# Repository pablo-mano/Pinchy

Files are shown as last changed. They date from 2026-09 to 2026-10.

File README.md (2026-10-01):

# Pinchy

**TODO — Firmware:** No firmware source code or flashable binaries are included in this repository. Firmware development and publication are deferred. See [TODO](TODO.md).

**A raspberry desktop companion by Paweł Manowiecki · [X: @pawel_mano](https://x.com/pawel_mano)**

[Polski](README_PL.md) · [Live 3D explorer](https://pablo-mano.github.io/Pinchy/) · [Print files](printing/README.md) · [BOM](electronics/BOM.md) · [Wiring](electronics/WIRING.md) · [Assembly](docs/ASSEMBLY.md) · [Films](videos/README.md)

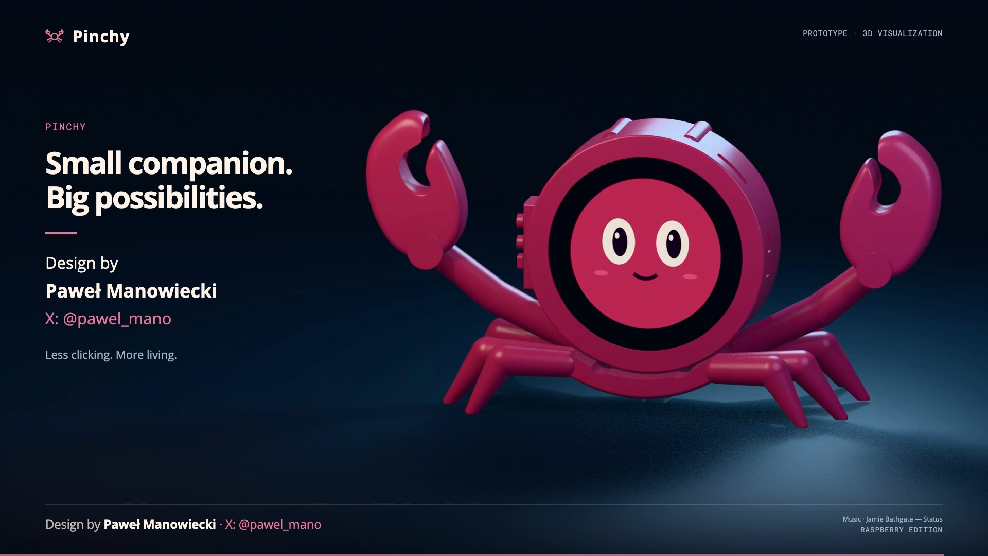
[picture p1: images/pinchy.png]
Pinchy — raspberry desktop companion


“**Hey Pinchy!**” — a small crab-shaped companion built around the **Waveshare ESP32-S3-Touch-LCD-2.1B, SKU 30697**. The current enclosure has a shaped screen seat, side controls, four M2 board mounts, a removable rear cover and an interchangeable D1 slide-and-click base. Complete leg pairs leave room for USB cables.

**Release status: mechanical prototype and audio fit/wiring study.** This repository includes printable parts and build documentation. Final audio/battery holders, electrical validation and functional voice-assistant firmware are still unfinished. The films are demonstrations on sample data. Start with [what can be built today](docs/BUILD_STATUS.md).

## Start here

1. Read the [BOM](electronics/BOM.md) and confirm the board variant — **30697 / 2.1B**, nominal Ø71.8 mm glass.
2. Print the screen-fit and D1 coupons using the [prepared Bambu P2S projects](printing/README.md).
3. Follow the [assembly guide](docs/ASSEMBLY.md) and validate mechanical fits.
4. Study the [connection diagram and cable plan](electronics/WIRING.md) before bench-testing the optional audio components.
5. Review the [firmware status](docs/FIRMWARE.md) and [remaining milestones](docs/BUILD_STATUS.md) before expecting working voice or online integrations.

## Print and edit

Target: **Bambu Lab P2S · 0.4 mm nozzle · Generic PLA · Textured PEI · 100% scale**. Raspberry reference color: `#C74565`.

| Download | Contents |
|---|---|
| [Plate 01](printing/plates/01_B_Proba_i_przyciski_P2S_PLA.3mf) | Screen-fit coupon, controls and spares |
| [Plate 02](printing/plates/02_B_Obudowa_P2S_PLA.3mf) | Front bezel, central shell and rear cover |
| [Plate 03](printing/plates/03_B_Nogi_i_szczypce_P2S_PLA.3mf) | D1 leg base and claws |
| [Plate 04](printing/plates/04_D1_Proba_mocowania_P2S_PLA.3mf) | D1 interface coupons — test before the full base |
| [STL parts](printing/stl/) | Individual print-oriented parts and coupons |
| [STEP parts](printing/step/) | Editable printed-part solids and [D1 receiver template](printing/step/D1_receiver_interface_TEMPLATE.step) |

All four plates total approximately **12 h 17 min / 148.36 g** in the saved slicer estimates. Print coupons first and allow material for retries. [Printing instructions](printing/README.md).

## Interactive exploded view

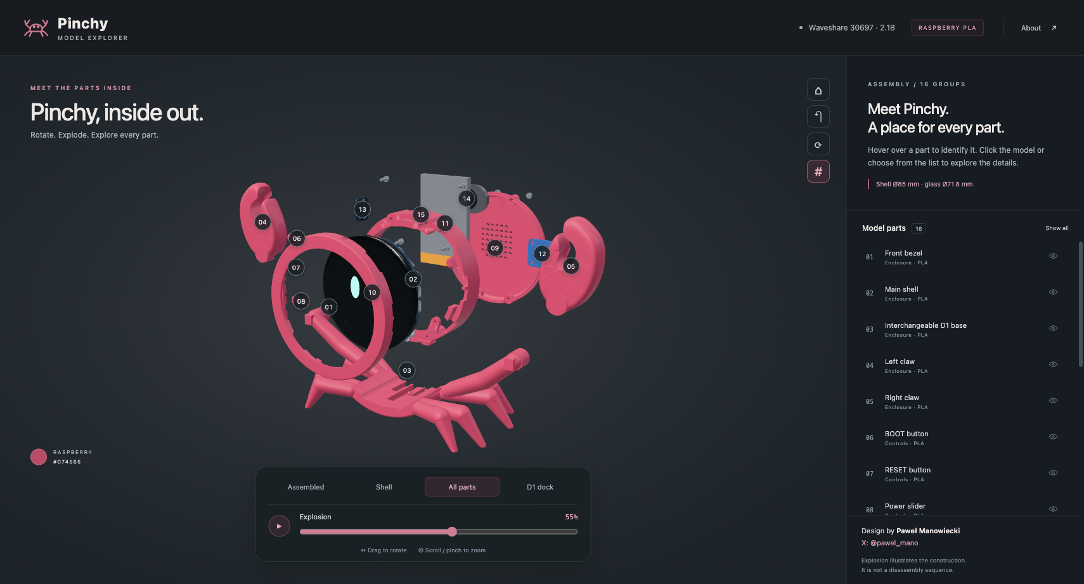
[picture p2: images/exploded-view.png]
Pinchy exploded-view explorer


[Open/download the standalone HTML](site/index.html): rotation, zoom, 16 part groups with tooltips, an explosion slider, isolation controls and a D1 base view. It works offline and has no backend. The viewing mesh is simplified; use the STL/STEP/3MF files for printing.

**[Open the live interactive explorer →](https://pablo-mano.github.io/Pinchy/)**

The [GitHub Pages workflow](.github/workflows/pages.yml) publishes `site/` from `main`. [Deployment and update instructions](docs/PUBLISHING.md).

## Product films

Both editions include the “Hey Pinchy!” wake phrase, OpenAI TTS voices, the InPost/email/calendar/theater scenario, exploded assembly, D1 base and full orbit. **58⅔ seconds**, with cuts on the beat of **Jamie Bathgate — Status** and readable dialogue over a reduced music level.

| Language | Full HD | Smaller full-length file |
|---|---|---|
| English | [1080p](videos/Pinchy_EN_1080p.mp4) | [720p](videos/Pinchy_EN_720p.mp4) |
| Polski | [1080p](videos/Pinchy_PL_1080p.mp4) | [720p](videos/Pinchy_PL_720p.mp4) |

[Subtitles and media details](videos/README.md). The visible author credit is **Paweł Manowiecki · X: @pawel_mano** throughout.

## Build documentation

- **[Photo wiring diagram (interactive)](https://pablo-mano.github.io/Pinchy/wiring/)** · [PNG](electronics/03_physical_connections.png) · [PDF A3](electronics/03_physical_connections.pdf) · [SVG](electronics/03_physical_connections.svg) · [source and assumptions](electronics/physical_wiring/README.md). Includes the Akyga LP503759 1350 mAh battery and the DFRobot DFR0954 amplifier variant; bench validation remains pending.

- [BOM with quantities and fit status](electronics/BOM.md) · [CSV](electronics/BOM.csv).
- [Wiring guide](electronics/WIRING.md) · [diagram SVG](electronics/01_connection_diagram.svg) · [diagram PNG](electronics/01_connection_diagram.png) · [netlist CSV](electronics/connections.csv).
- [Cable routing SVG](electronics/02_cable_routing_plan.svg) · [routing coordinates](electronics/cable_routes.json) · [3D cable study](electronics/Pinchy_cable_plan.glb).
- [Assembly guide and tools](docs/ASSEMBLY.md) · [D1 dimensions in Polish](docs/D1_INTERFACE_PL.md).
- [Firmware requirements](docs/FIRMWARE.md) · [build status and remaining work](docs/BUILD_STATUS.md).
- [Source credits and third-party notices](THIRD_PARTY_NOTICES.md).
- [Validation and its limits](docs/VALIDATION.md).
- [Delivery manifest](manifest.json): file sizes and SHA-256 hashes.

The package preserves the established mechanical part identifiers from revision B/D1 (previously C03B) for consistency between print and CAD files. The product name is **Pinchy**.

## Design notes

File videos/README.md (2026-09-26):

# Pinchy films

| Language | Full HD | Smaller full-length copy | Subtitles |
|---|---|---|---|
| Polski | [1080p](Pinchy_PL_1080p.mp4) | [720p](Pinchy_PL_720p.mp4) | [SRT](Pinchy_PL.srt) |
| English | [1080p](Pinchy_EN_1080p.mp4) | [720p](Pinchy_EN_720p.mp4) | [SRT](Pinchy_EN.srt) |

Both editions run **58⅔ seconds at 24 fps**. Wake phrase: **“Hey Pinchy!”**. Scenario: InPost parcel, notification email to Ola, today's calendar and theater at 14:00 with a 13:00 reminder. These are clearly labeled simulated interactions with sample data.

Project and design: **Paweł Manowiecki · X: @pawel_mano**. The attribution remains visible throughout both films. Voices: **OpenAI TTS**, marin for the person and cedar for Pinchy.

Music: **Jamie Bathgate — Status**, from the file provided for this project. The edit uses an excerpt starting at 2⅔ s, with six major scene cuts on a 90 BPM grid; calendar/theater card changes are also on beats. Music is reduced under dialogue, and the final two beats fade out. The underlying track remains third-party material; see [notices](../THIRD_PARTY_NOTICES.md).

The exploded model, D1 base demonstration and full orbit show the current mechanical design. Motion illustrates assembly; it does not imply powered claws, legs or a motorized base.

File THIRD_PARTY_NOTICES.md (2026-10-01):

# Credits and third-party material

**Pinchy project/design:** Paweł Manowiecki · [X: @pawel_mano](https://x.com/pawel_mano).

No blanket open-source license for the original Pinchy design files has been selected in this preparation step. Third-party terms remain separate; this attribution notice does not relicense those materials.

## Web renderer

The self-contained explorer embeds **Three.js 0.180.0**, distributed under MIT. Its copyright/license notice is included in the HTML and in [THREE_MIT.txt](licenses/THREE_MIT.txt). Source: [Three.js](https://github.com/mrdoob/three.js).

## Photographic wiring diagram

The photo-based wiring sheet and its interactive page include reference images from **Waveshare** (ESP32-S3-Touch-LCD-2.1 rear PCB), **Adafruit** (SPH0645 #3421), **DFRobot** (DFR0954 module rendering) and **Kamami** (Akyga AKY0107 battery and speaker 560816 product photos). The source images are cropped or rotated for presentation; the diagram adds pin labels and proposed connections. Copyright and any applicable terms remain with their respective rights holders; no new license to those images is asserted. [Sources, assumptions and validation limits](electronics/physical_wiring/README.md).

## Hardware reference geometry

- **Waveshare ESP32-S3-Touch-LCD-2.1B:** reference geometry derived from the official manufacturer drawing archive. The embedded simplified viewing model represents the purchased board/display, not a printable replacement. [Manufacturer resources](https://docs.waveshare.com/ESP32-S3-Touch-LCD-2.1/Resources-And-Documents) · [B drawing archive](https://files.waveshare.com/wiki/ESP32-S3-Touch-LCD-2.1/ESP32-S3-Touch-LCD-2.1B-Drawing.zip). No new license for Waveshare material is asserted here.
- **Adafruit CAD Parts:** battery #258, speaker #3923 and amplifier #3006 from [Adafruit_CAD_Parts](https://github.com/adafruit/Adafruit_CAD_Parts), commit `6f52ee4d48df0e7118d2d82f485cb572051a24fe`. MIT, copyright Adafruit Industries; [license copy](licenses/ADAFRUIT_CAD_MIT.txt). Web geometry is simplified for display.
- **SPH0645 microphone #3421:** locally reconstructed from [Adafruit I²S Microphone Breakout PCB](https://github.com/adafruit/Adafruit-I2S-Microphone-Breakout-PCB), commit `bb0dfa60919c5679f676e0af41958bece6294b05`, and the [Knowles datasheet](https://cdn-shop.adafruit.com/product-files/3421/i2S%20Datasheet.PDF). This is a reconstruction, not an official full-module STEP. That derived microphone reference remains under **CC BY-SA 3.0**, with attribution to Adafruit Industries; [license copy](licenses/ADAFRUIT_MIC_CC_BY_SA_3.txt). PCB thickness, solder and small component geometry are approximations.

## Film music and voices

Music in the finished films: **Jamie Bathgate — Status**, using the MP3 supplied for this project. Its embedded tags identify the album *Aground* and Art-list. Music rights remain with the relevant rights holders; this repository does not grant a license to extract or reuse the track. The standalone source MP3 is not included. Public release of the finished films should use the project owner's applicable music license.

Voices were synthesized with **OpenAI gpt-4o-mini-tts**, using `marin` and `cedar`. The “Hey Pinchy!” line was generated separately in Polish and English. The films disclose their use of OpenAI TTS and simulated interaction data.

Product names and trademarks identify compatible/reference hardware and do not imply endorsement.

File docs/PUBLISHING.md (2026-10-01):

# Pinchy — GitHub and Pages

- Repository: [pablo-mano/Pinchy](https://github.com/pablo-mano/Pinchy)
- Interactive explorer: [pablo-mano.github.io/Pinchy](https://pablo-mano.github.io/Pinchy/)
- Interactive wiring: [pablo-mano.github.io/Pinchy/wiring/](https://pablo-mano.github.io/Pinchy/wiring/)
- Deployment runs: [Publish Pinchy explorer](https://github.com/pablo-mano/Pinchy/actions/workflows/pages.yml)

The workflow publishes only `site/` from `main`. `index.html` bundles the model, renderer and styles; no Node build, API key or backend is required. Print files and videos remain repository downloads. Firmware is [TODO](../TODO.md), with no device source code or binaries included.

## Update the published page

1. Update `site/index.html`, preserving its embedded assets and attribution.
2. For the wiring explorer, edit `electronics/physical_wiring/page.html` and/or `build.py`, then run `python3 electronics/physical_wiring/build.py` with Pillow installed. This refreshes the repository HTML and the Pages HTML/SVG. After drawing changes, also regenerate the PNG and A3 PDF and copy the PDF into `site/wiring/`. Preserve the relative navigation links between both explorers.
3. Refresh `manifest.json` file sizes and SHA-256 hashes, then commit and push the update to `main`.
4. Check the Pages workflow above. A successful deployment updates the same public URL.

Pages uses **Settings → Pages → Build and deployment → Source: GitHub Actions**. To redeploy without another content change, open **Actions → Publish Pinchy explorer → Run workflow** on `main`.

The [standalone HTML](../site/index.html) also opens from disk. A GitHub `blob` link shows the file rather than running the explorer; use the Pages URL for the interactive view.

## Publish a fork

Enable GitHub Actions as the Pages source in your fork, run the workflow, and replace the original repository/site URLs with those of your fork. Keep `.github/workflows/pages.yml` and the complete `site/` folder. The workflow expects `main`; adapt its branch filter if your default branch differs.

Configuration follows the [GitHub Pages custom workflow documentation](https://docs.github.com/en/pages/getting-started-with-github-pages/using-custom-workflows-with-github-pages).

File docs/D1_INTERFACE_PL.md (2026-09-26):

# Pinchy — wymienna podstawa D1

Dwie prowadnice typu jaskółczy ogon przenoszą obciążenie. Zaokrąglony garb na sprężystym języczku zatrzymuje podstawę w położeniu końcowym. Języczek jest częścią podstawy, bez osobnej sprężyny, zębatki i wkrętów. To prototyp do fizycznej próby w PLA.

*Wycinki rozłożone obok siebie, obie powierzchnie styku skierowane do góry. Lewy wycinek korpusu jest odwrócony względem położenia w krabie.*

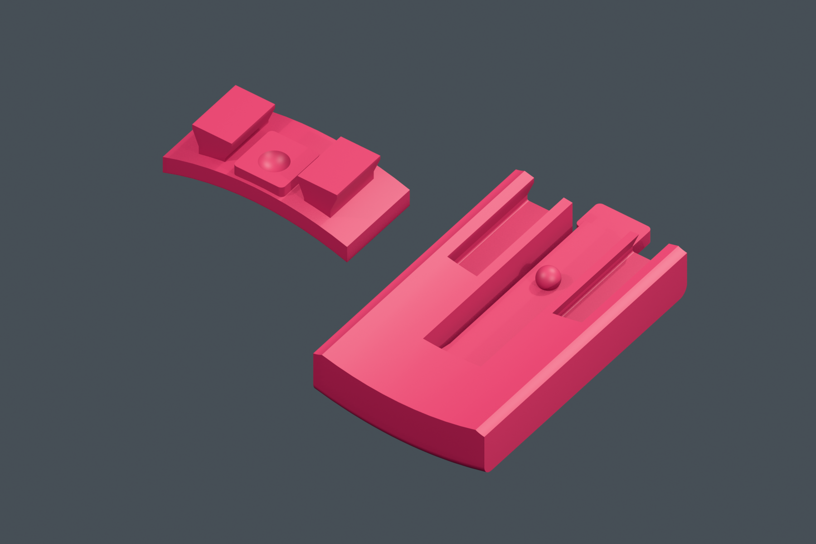
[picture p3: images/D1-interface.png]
Złącze D1 — wycinki obu części


## Zakładanie i wymiana

1. Chwyć pancerz, ustaw podstawę około 20 mm przed pozycją końcową, od strony ekranu. Otwarty tył rowków podstawy skieruj na szyny pod korpusem.
2. Przesuń podstawę ku tyłowi urządzenia do ogranicznika. Garb powinien schować się na języczku, a następnie wskoczyć w wgłębienie. Nie wymuszaj ruchu przy oporze.
3. Aby zdjąć podstawę, podeprzyj korpus i naciśnij wystającą tylną łopatkę od spodu **w dół, od pancerza**. Trzymając ją odchyloną, wysuń podstawę do przodu, w stronę ekranu. Szczypce mogą zostać na podstawie.

Podstawę wymienia się bez otwierania komory elektroniki. Przed zmianą odłącz zewnętrzne przewody i nie podnoś całego urządzenia za samą podstawę do czasu fizycznej próby utrzymania obciążenia.

## Próbnik do PLA

Najpierw otwórz [płytę 04](../printing/plates/04_D1_Proba_mocowania_P2S_PLA.3mf). Zawiera wycinek korpusu z obiema szynami i wycinek podstawy z kompletnym języczkiem. Około **48 min / 7,92 g PLA**, Bambu Lab P2S 0,4 mm, warstwa 0,16 mm. Osobne STL są w `stl/00_D1_*` i mają orientację do druku.

Usuń podpory z rowków, przestrzeni pod języczkiem i wokół ogranicznika. Sprawdź bez elektroniki: swobodne prowadzenie, lekki klik, brak samoczynnego wysuwania oraz łatwe zwolnienie języczkiem. Powtórz kilka razy, obejrzyj nasadę pod kątem pęknięć i zbielenia PLA. W razie ciasnego prowadzenia popraw parametr `CLEARANCE` w generatorze, nie skaluj całego STL. Siła kliku, nośność, trwałość i pełzanie PLA nie zostały zmierzone. Unikaj pozostawiania języczka stale odgiętego lub w nagrzanym samochodzie.

Po udanej próbie wydrukuj razem aktualny **02_crab_rear** i **03_crab_base**. Starszy korpus i starsza podstawa nie mają zgodnego interfejsu D1. Przód B, pokrywa B, szczypce i nakładki przycisków mogą zostać z poprzedniej wersji C03B.

## Interfejs dla kolejnych designów

[Szablon gniazda podstawy STEP](../printing/step/D1_receiver_interface_TEMPLATE.step) jest dokładnym wycinkiem gotowej podstawy z rowkami, sprężyną i ogranicznikiem. Nie obracaj go względem złożenia STEP. Zachowaj cały wycinek i dobuduj nową podstawę do jego zewnętrznych boków; nie wypełniaj rowków ani pustej przestrzeni wokół języczka. Sprawdź na pełnym złożeniu drogę wsuwania, dostęp do łopatki i USB. Szablon daje wspólne mocowanie, ale nie gwarantuje stabilności dowolnego nowego designu.

Układ współrzędnych CAD: X w prawo, Y do góry, Z ku tyłowi; środek ekranu X=Y=0. Podłoga gotowego kraba Y=−56 mm. Wszystkie poniższe wymiary są w mm, skala 1:1.

| Cecha | Wartość |
|---|---|
| Osie prowadnic X | −8 i +8; rozstaw 16 |
| Odcinek szyn korpusu Z | 13…22; długość 9 |
| Profil jednej szyny | szyjka 4, rozszerzenie 6 |
| Spód szyny Y | −45,6 |
| Luz profilu rowka | odsunięcie konturu o 0,25, nie powiększenie całego modelu |
| Początek rowków / przedni ogranicznik Z | 13 |
| Otwarty koniec rowków | ku dodatniemu Z, od tyłu podstawy |
| Języczek | grubość 1,2; wolna szerokość 6,4; długość do łopatki ok. 32 |
| Garb | kula R1,6; środek (0; −44,8; 20) |
| Gniazdo garbu | kula R2,2 o tym samym środku |
| Ogranicznik ugięcia przy garbie | nominalna droga 1,35 |
| Próba rozłączenia CAD | przybliżone odchylenie garbu ok. 1,05; wysuw 20 |

Dokładny kontur szyn i szablon są zapisane w STEP oraz `design/waveshare_crab_21b/dock.py`. Współrzędne są wspólne z całym krabem; STL próbników są obrócone i wyzerowane na stole drukarki.

## Weryfikacja

`dock_validation.json`: brak przenikania korpusu i podstawy w pozycji końcowej, zgodność próbników, zatrzymanie przesuwu na garbie i ograniczniku, utrzymanie poprzeczne przez prowadnice. Sprawdzono 41 położeń wysuwania co 0,5 mm, wraz ze szczypcami. Po odsunięciu języczka nie znaleziono kolizji z przodem, korpusem ani pokrywą.

Ugięcie zastąpiono obrotem geometrii swobodnej części języczka o 3°. To kontrola miejsca, **nie analiza naprężeń ani wyznaczenie siły zwolnienia**. Wydruk próbny jest potrzebny przed uznaniem tego połączenia za gotowe do regularnego użytkowania.

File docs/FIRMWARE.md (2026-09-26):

# TODO — Pinchy firmware

**TODO: implement, validate and publish firmware in a future release. No firmware source code, flashable binaries or working integrations are included in this repository.** The product films use rendered faces and prerecorded OpenAI TTS; they are not recordings of running hardware.

Start from the [official Waveshare documentation and examples](https://docs.waveshare.com/ESP32-S3-Touch-LCD-2.1), confirming support for the actual **2.1B / SKU 30697** board. Display, touch, GPIO-expander, USB switching and battery behavior must be checked against the physical board revision.

The proposed audio mapping is BCLK GPIO19, WS GPIO20, microphone DOUT into GPIO44 and amplifier DIN from GPIO43. These overlap native USB and UART, including the board's multiplexer. See the [wiring requirements](../electronics/WIRING.md) before using these pins. A preliminary bench format is Philips I²S at 48 kHz with two 32-bit slots; correct SPH0645 data alignment and sample conversion still need testing.

A future reproducible software release needs:

- A pinned framework/toolchain version, exact board configuration and clean build command.
- A tested binary, flash offsets, programming/boot procedure and recovery instructions.
- Display/touch bring-up, GPIO mapping, shared I²S RX/TX, sample-format conversion and volume limits.
- Wi-Fi provisioning, credential storage, OTA updates and a service mode that releases shared audio/USB pins.
- “Hey Pinchy!” detection or an explicitly documented push-to-talk first version.
- Speech recognition, dialogue service, OpenAI TTS playback and face animation tied to actual playback.
- Mail, calendar and parcel connectors with authentication and a clear boundary between demonstration and real actions.
- Configuration examples containing placeholders only; no API keys, mailbox tokens or private calendars in Git.

Keep API credentials out of the public repository. No existing `key.txt`, runtime `.env`, or prior account configuration is included in this package.

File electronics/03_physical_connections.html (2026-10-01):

PinchyWIRING EXPLORER

Waveshare 30697 · 2.1BBENCH PROPOSAL

Pin table ↘

FOLLOW EVERY CONNECTION

# Pinchy, connected.

Real components. Labeled pins. One signal at a time.

5 components · 14 connections

⊞ Fit view−100%+

Click a wire to highlight its signal.
Zoom in, then scroll to explore.Connection table ↘

WIRING / ALL SIGNALS

## Every pin. Every connection.

Select a signal below or click a wire to trace its connections across the modules.

Dashed power connections require verification before connecting.

### Signal groups 9

Show all

3V3 · microphoneJ9.6 · MIC.3V↗GND · common groundJ9.5 · MIC.GND · MIC.SEL↗BCLK · GPIO19J9.3 · MIC.BCLK · AMP.BCLK↗WS / LRCLK · GPIO20J9.4 · MIC.LRCL · AMP.LRC↗DOUT · GPIO44 + 100 kΩMIC.DOUT · J9.10 · RPD1.1↗DIN · GPIO43J9.9 · AMP.DIN↗Power · verify firstBAT.+ · J1.1 · BAT.-↗SPK+ · speakerAMP.SPK+ · SPK.+↗SPK− · speakerAMP.SPK- · SPK.-↗

↓ PDF / A3↓ SVG

Design by Paweł Manowiecki
X: @pawel_mano (https://x.com/pawel_mano)

FROM PAD TO PAD

## Connection table

This is a bench-test proposal, not a validated assembly. The confirmed battery is the Akyga AKY0107 / LP503759, 1350 mAh. The DFRobot DFR0954 amplifier is assumed from the shopping list. The 3D exploded view still uses the earlier Adafruit reference parts. Photos show module orientation; the J9 and J1 expansions show schematic pin numbers, not connector faces. Verify the harness pinout with a meter.

Signal | From | To | Note
3V3 | J9.6 / 3V3 | MIC 3V | 3.3 V
GND | J9.5 / GND | MIC GND | Common ground
SEL | MIC SEL | MIC GND | Left channel
BCLK | J9.3 / D− / GPIO19 | MIC BCLK + AMP BCLK | Shared branch
WS | J9.4 / D+ / GPIO20 | MIC LRCL + AMP LRC | Shared branch
MIC DATA | MIC DOUT | J9.10 / RXD / GPIO44 | Microphone data
RPD1 | MIC DOUT | 100 kΩ → GND | Additional parallel pull-down resistor
AMP DATA | J9.9 / TXD / GPIO43 | AMP DIN | Amplifier audio data
AMP GND | J9.1 / GND | AMP GND | Amplifier power return
AMP VCC | Waveshare VCC / U5 VIN / C14 | AMP VCC | Conditional: verify physical tap and 3.3–5 V range
SPK+ | AMP SPK+ | Red speaker lead | 8 Ω / 1 W
SPK− | AMP SPK− | Black speaker lead | Do not connect to GND
BAT+ | Akyga BAT+ | J1.1 BAT | Conditional: adapt the connector and charge current
BAT− | Akyga BAT− | J1.2 GND | Verify polarity with a meter

CHECK THE SOURCE

## Hardware references

- Waveshare — shared 2.1 / 2.1B documentation (https://docs.waveshare.com/ESP32-S3-Touch-LCD-2.1) and J9, J1 and power schematic (https://files.waveshare.com/wiki/ESP32-S3-Touch-LCD-2.1/ESP32-S3-Touch-LCD-2.1_schematic_diagram.pdf). The rear PCB photo is from the 2.1 product page; the manufacturer publishes a shared schematic. Check your board revision before soldering.
- Adafruit #3421 — pinout (https://learn.adafruit.com/adafruit-i2s-mems-microphone-breakout/pinouts) and Knowles — 100 kΩ DATA pull-down (https://cdn-shop.adafruit.com/product-files/3421/i2S%20Datasheet.PDF#page=7). The microphone photo shows the sound-port side with pin labels.
- DFRobot DFR0954 — module, pins and 3.3–5 V supply (https://wiki.dfrobot.com/dfr0954/). The manufacturer rendering is rotated 90°, not mirrored. Verify Waveshare VCC with a low battery too; operation over the full battery range has not been validated.
- Akyga AKY0107 datasheet (https://www.tme.eu/Document/d09d785c980e096e8a2305b0492fc05e/AKY0107.pdf): maximum charge and discharge current 1C = 1.35 A; standard charge 0.2C, fast charge 0.5C. These are battery ratings, not measurements of the Waveshare charger. Its published schematic suggests an approximately 2 A setting; adjust and measure before charging this pack.
- Kamami — Akyga product photo (https://kamami.pl/akumulatory/1202750-akumulator-litowo-polimerowy-akyga-aky0107-lp503759-li-po-3-7v-1350mah-pcm-jst-2-54-2-pin-150mm-5906574243544.html) and speaker 560816 photo (https://kamami.pl/glosniki/560816-glosnik-z-przewodami-8-1w-5906623455089.html).

Line colors identify signals, not factory J9 wire colors. Dots mark electrical junctions; crossings without dots do not connect. Component photos are not at a common scale. Images remain the property of their manufacturers or seller; this diagram does not change their licenses.

Pinchy · physical parts and connections · 01 Oct 2026← Back to exploded view

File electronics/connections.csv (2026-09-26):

net | from | to | status
MIC_3V3 | Waveshare J9.6 3V3 | SPH0645 3V | proposed
GND | Waveshare J9.1 or J9.5 GND | SPH0645 GND and MAX98357 GND | proposed
BCLK | Waveshare J9.3 GPIO19 | SPH0645 BCLK and MAX98357 BCLK | shared with native USB
WS | Waveshare J9.4 GPIO20 | SPH0645 LRCLK and MAX98357 LRC | shared with native USB
MIC_DATA | SPH0645 DOUT | Waveshare J9.10 GPIO44 | UART mux must enable external connector
AMP_DATA | Waveshare J9.9 GPIO43 | MAX98357 DIN | UART mux must enable external connector
MIC_SEL | SPH0645 SEL | SPH0645 GND | left channel
MIC_DATA_PULLDOWN | SPH0645 DOUT | 100k resistor to GND | additional passive not included in CAD
AMP_POWER | Waveshare VCC net at U5 VIN or C14 VCC side | MAX98357 VIN | physical solder point and current capacity to verify
SPK_PLUS | MAX98357 OUT+ | Speaker terminal 1 | BTL neither terminal is GND
SPK_MINUS | MAX98357 OUT- | Speaker terminal 2 | BTL neither terminal is GND
BAT_PLUS | Protected LiPo BAT+ | Waveshare J1.1 BAT | after charger-current modification and polarity check
BAT_MINUS | Protected LiPo BAT- | Waveshare J1.2 GND | verify matching connector and polarity

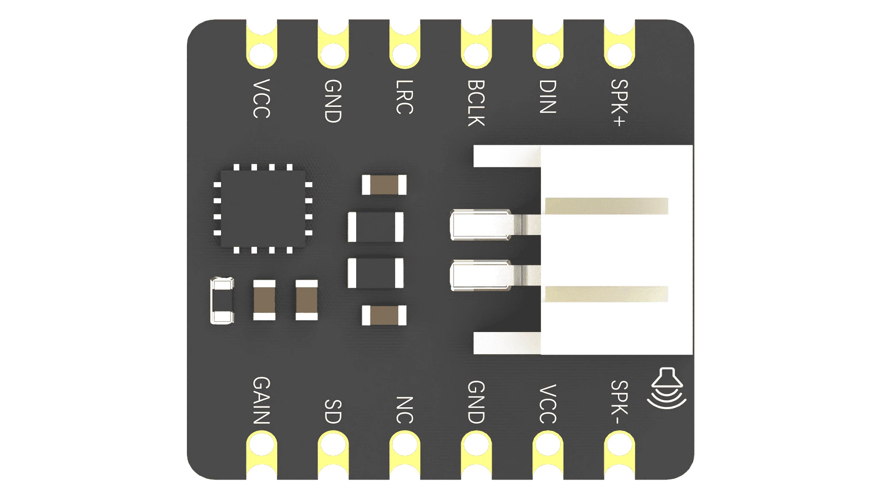
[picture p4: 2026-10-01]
electronics/physical_wiring/assets/dfr0954-pinout.webp

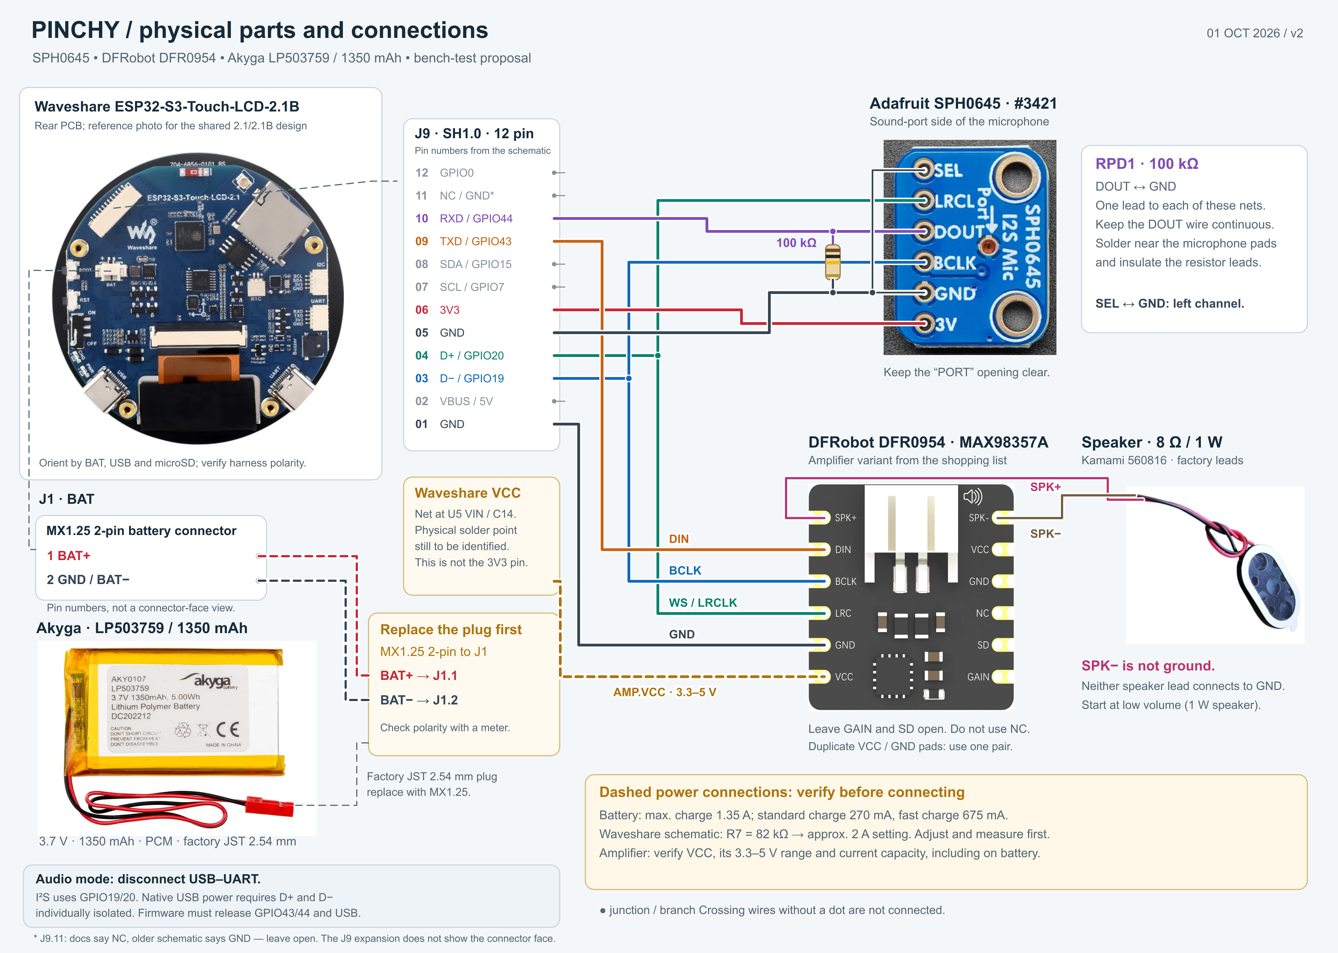
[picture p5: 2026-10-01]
electronics/03_physical_connections.png

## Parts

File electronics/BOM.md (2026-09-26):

# Pinchy — bill of materials

[Download CSV](BOM.csv) · [Wiring](WIRING.md) · [Build status](../docs/BUILD_STATUS.md)

This is the current CAD-reference BOM. Audio, battery and harness items are prototype candidates; their status is explicit below. Prices and stock are not part of this snapshot. The enclosure uses **Waveshare 30697 / 2.1B**.

| Ref | Qty | Part | Status / fit |
|---|---:|---|---|
| WS1 | 1 | [Waveshare ESP32-S3-Touch-LCD-2.1B](https://www.waveshare.com/esp32-s3-touch-lcd-2.1.htm) | Required / supplied by builder. Current mechanical reference; glass Ø71.8 mm. Not the flat 28169 model. |
| MIC1 | 1 | [Adafruit SPH0645 I2S microphone](https://www.adafruit.com/product/3421) | Audio prototype. Matches reconstructed CAD; final holder and acoustic channel pending. |
| AMP1 | 1 | [Adafruit MAX98357A I2S amplifier](https://www.adafruit.com/product/3006) | Audio prototype. Matches CAD PCB; terminal block reserved separately; VCC tap unverified. |
| SPK1 | 1 | [Adafruit mini oval speaker 8 ohm 1 W](https://www.adafruit.com/product/3923) | Audio prototype. Matches CAD reference; final cradle and acoustic seal pending. |
| BAT1 | 0–1 | [Protected 1S LiPo, 1200 mAh reference](https://www.adafruit.com/product/258) | Conditional / not approved for direct connection. Reference pack permits <=500 mA charging; verify and adapt actual board charger and connector first. |
| RPD1 | 1 | [100 kΩ resistor](https://botland.com.pl/rezystory-przewlekane/20020-rezystor-justpi-tht-cf-weglowy-14w-100k-30szt-5904422329082.html) | Audio prototype. Microphone DOUT to GND pull-down; insulate the leads. |
| J9C | 1 | [JST-SH 1.0 mm 12-pin breakout lead](https://kamami.pl/przewody-jst/1184455-przewod-jst-sh-10-12-pin-10cm-a-a-5906623447800.html) | Verify supplied accessories. Check mating and pin-1 orientation; identify conductors by continuity. |
| J1C | 0–1 | Battery harness mating the actual MX1.25 2-pin socket | Unresolved. Not JST-PH; verify connector housing and BAT+/GND; do not use RTC socket. |
| SIG | as needed | Flexible stranded signal wire 30 AWG | Prototype harness. Planning diameter; route lengths and final slack in cable_routes.json. |
| PWR | as needed | Flexible stranded power/speaker wire 26–28 AWG | Prototype harness. Twist OUT+/OUT−; neither speaker terminal is ground. |
| USB1 | 1 | USB data cable for programming | Service. Plug body <=12×6 mm and <=15 mm long assumed by CAD. |
| USB2 | as needed | Verified audio-mode USB power lead | Unresolved. A generic charge-only cable may short data lines; test individually, including between them. |
| PSU1 | 1 | Regulated 5 V USB supply | Bench supply. Select after measuring board, display and audio current. |
| M2 | 4 | M2 × 5 mm machine screws | Required. Board mounting; check actual usable thread depth before tightening. |
| SC25 | 4 | Ø2.5 × 25 mm screws for plastic | Required. Enclosure; ordinary M2.5 machine screws are not an automatic substitute. |
| PAD | as needed | Soft glass support strips | Required / fit to sample. Nominal axial allowances ~0.2 mm front and ~0.4 mm rear; verify compression. |
| INS | as needed | Heat-shrink, insulating tape, solder and flux | Assembly. Do not obstruct microphone port, rails or latch. |
| PLA | ~150 g minimum | Raspberry Generic PLA | Required. Four prepared plates total 148.36 g estimated; allow extra for retries. |
| DEC | TBD | Amplifier decoupling components | Unresolved. No validated values or final board mounting solution supplied. |
| CHG | TBD | Charge-current adjustment components | Unresolved. Do not select a resistor from a guessed board revision. |
| MOUNT | TBD | Battery/audio holders, microphone gasket and speaker seal | Not yet designed. Existing printable parts mount Waveshare, not the additional audio parts. |

## Local purchasing alternatives

These are reference links from the earlier sourcing work, not claims of current availability or fit. Do not mix alternative dimensions into the current CAD without checking them.

- [Kamami SPH0645 #3421](https://kamami.pl/moduly-z-mikrofonami-i-detektory-dzwieku/564318-modul-z-mikrofonem-mems-sph0645lm4h-b-5906623429523.html): the same microphone board as the CAD reconstruction.
- [Botland DFRobot DFR0954 MAX98357A](https://botland.com.pl/odtwarzacze-mp3-wav-ogg-midi/21992-modul-wzmacniacza-audio-max98357-dfrobot-dfr0954-6959420922703.html): alternative to Adafruit #3006; different PCB, mounting and component heights.
- [Kamami 560816 speaker, 8 Ω / 1 W](https://kamami.pl/glosniki/560816-glosnik-z-przewodami-8-1w-5906623455089.html): 24 × 15 × 4.2 mm alternative, requiring a different cradle and seal.
- A battery is intentionally not marked as a drop-in purchase. Match actual charge current, dimensions, connector and polarity before selecting one.

The nine main printed parts are front bezel, central shell, D1 leg base, left/right claws, BOOT button, RESET button, power slider and rear cover. The 3MF plates include the fit coupons and spare controls. D1 uses a printed flexure; no separate metal latch or spring is required.

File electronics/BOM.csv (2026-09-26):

reference | category | quantity | part | manufacturer_or_spec | status | notes | reference_url
WS1 | electronics | 1 | Waveshare ESP32-S3-Touch-LCD-2.1B | 30697 | Required / supplied by builder | Current mechanical reference; glass Ø71.8 mm. Not the flat 28169 model. | https://www.waveshare.com/esp32-s3-touch-lcd-2.1.htm
MIC1 | electronics | 1 | Adafruit SPH0645 I2S microphone | 3421 | Audio prototype | Matches reconstructed CAD; final holder and acoustic channel pending. | https://www.adafruit.com/product/3421
AMP1 | electronics | 1 | Adafruit MAX98357A I2S amplifier | 3006 | Audio prototype | Matches CAD PCB; terminal block reserved separately; VCC tap unverified. | https://www.adafruit.com/product/3006
SPK1 | electronics | 1 | Adafruit mini oval speaker 8 ohm 1 W | 3923 | Audio prototype | Matches CAD reference; final cradle and acoustic seal pending. | https://www.adafruit.com/product/3923
BAT1 | power | 0–1 | Protected 1S LiPo, 1200 mAh reference | Adafruit 258 | Conditional / not approved for direct connection | Reference pack permits <=500 mA charging; verify and adapt actual board charger and connector first. | https://www.adafruit.com/product/258
RPD1 | electronics | 1 | 100 kΩ resistor | 100k | Audio prototype | Microphone DOUT to GND pull-down; insulate the leads. | https://botland.com.pl/rezystory-przewlekane/20020-rezystor-justpi-tht-cf-weglowy-14w-100k-30szt-5904422329082.html
J9C | cables | 1 | JST-SH 1.0 mm 12-pin breakout lead | SH1.0 12P | Verify supplied accessories | Check mating and pin-1 orientation; identify conductors by continuity. | https://kamami.pl/przewody-jst/1184455-przewod-jst-sh-10-12-pin-10cm-a-a-5906623447800.html
J1C | cables | 0–1 | Battery harness mating the actual MX1.25 2-pin socket | TBD after inspection | Unresolved | Not JST-PH; verify connector housing and BAT+/GND; do not use RTC socket.
SIG | cables | as needed | Flexible stranded signal wire 30 AWG | insulation OD <=0.7 mm target | Prototype harness | Planning diameter; route lengths and final slack in cable_routes.json.
PWR | cables | as needed | Flexible stranded power/speaker wire 26–28 AWG | insulation and current to verify | Prototype harness | Twist OUT+/OUT−; neither speaker terminal is ground.
USB1 | cables | 1 | USB data cable for programming | USB-C device end | Service | Plug body <=12×6 mm and <=15 mm long assumed by CAD.
USB2 | cables | as needed | Verified audio-mode USB power lead | D+ and D− individually isolated | Unresolved | A generic charge-only cable may short data lines; test individually, including between them.
PSU1 | power | 1 | Regulated 5 V USB supply | load budget to verify | Bench supply | Select after measuring board, display and audio current.
M2 | hardware | 4 | M2 × 5 mm machine screws | head <=Ø3.8 × 2 mm | Required | Board mounting; check actual usable thread depth before tightening.
SC25 | hardware | 4 | Ø2.5 × 25 mm screws for plastic | head <=Ø4.8 mm | Required | Enclosure; ordinary M2.5 machine screws are not an automatic substitute.
PAD | consumables | as needed | Soft glass support strips | compressible insulating material | Required / fit to sample | Nominal axial allowances ~0.2 mm front and ~0.4 mm rear; verify compression.
INS | consumables | as needed | Heat-shrink, insulating tape, solder and flux | small joints | Assembly | Do not obstruct microphone port, rails or latch.
PLA | printing | ~150 g minimum | Raspberry Generic PLA | #C74565 visual target | Required | Four prepared plates total 148.36 g estimated; allow extra for retries.
DEC | electronics | TBD | Amplifier decoupling components | values after bench tests | Unresolved | No validated values or final board mounting solution supplied.
CHG | power | TBD | Charge-current adjustment components | after actual-board measurement | Unresolved | Do not select a resistor from a guessed board revision.
MOUNT | hardware | TBD | Battery/audio holders, microphone gasket and speaker seal | next mechanical revision | Not yet designed | Existing printable parts mount Waveshare, not the additional audio parts.

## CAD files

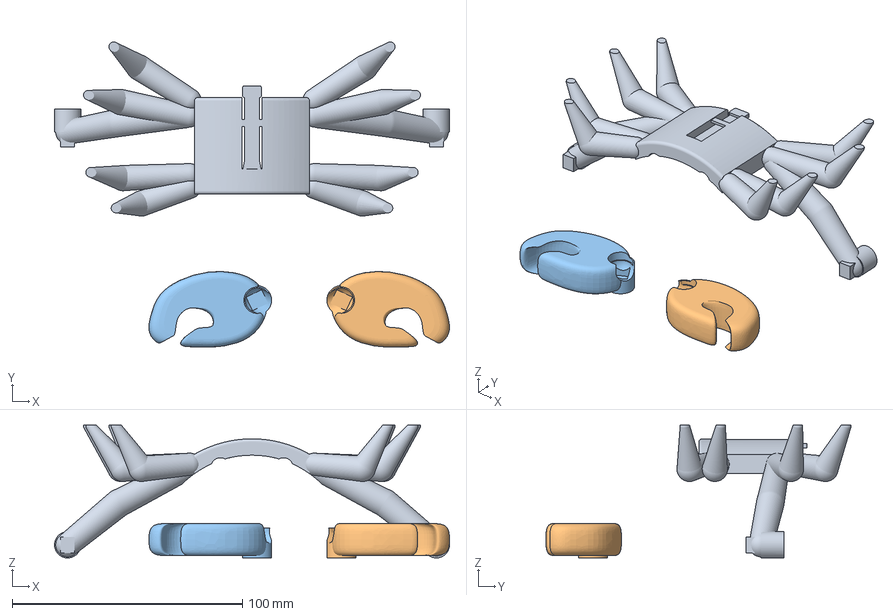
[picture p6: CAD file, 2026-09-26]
printing/plates/03_B_Nogi_i_szczypce_P2S_PLA.3mf
171.4 x 132.4 x 57.7 mm
03_crab_base.stl
04_claw_L.stl
05_claw_R.stl

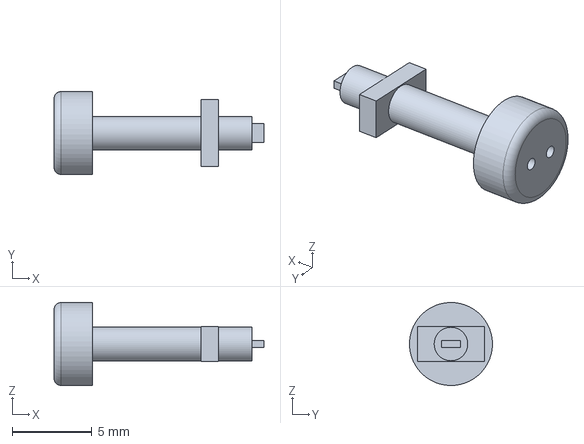
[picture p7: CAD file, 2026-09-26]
printing/step/07_button_RESET.step
13.1 x 5.20 x 5.20 mm

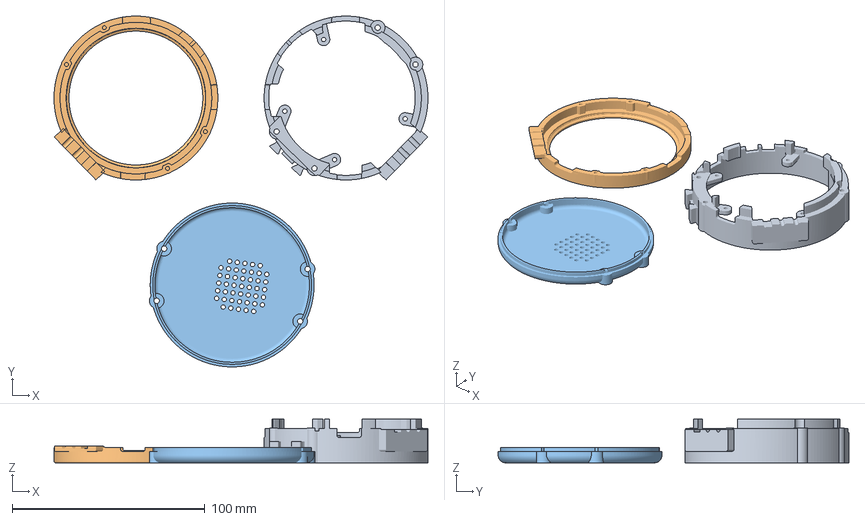
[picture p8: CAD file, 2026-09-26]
printing/plates/02_B_Obudowa_P2S_PLA.3mf
194.0 x 182.0 x 22.7 mm
02_crab_rear.stl
01_crab_front.stl
09_rear_service_cover.stl

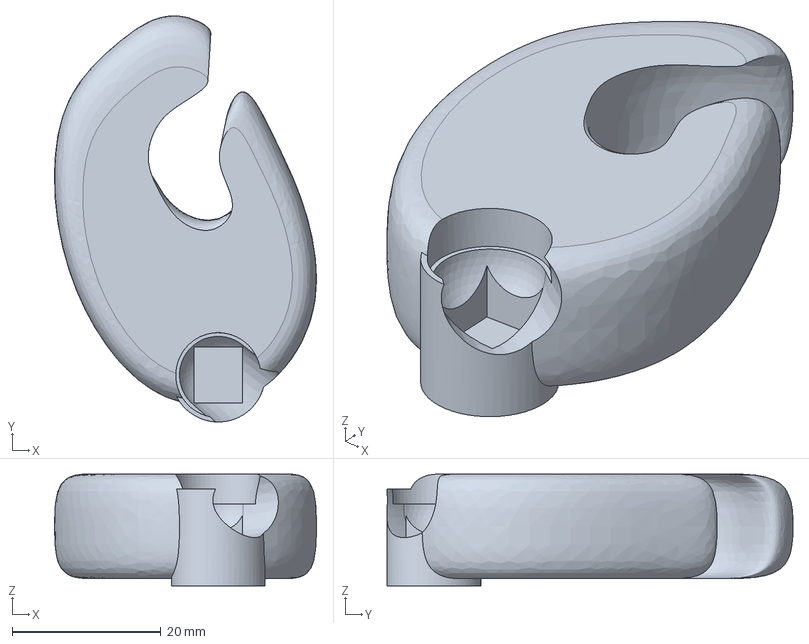
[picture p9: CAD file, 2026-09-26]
printing/step/04_claw_L.step
35.2 x 54.5 x 15.0 mm

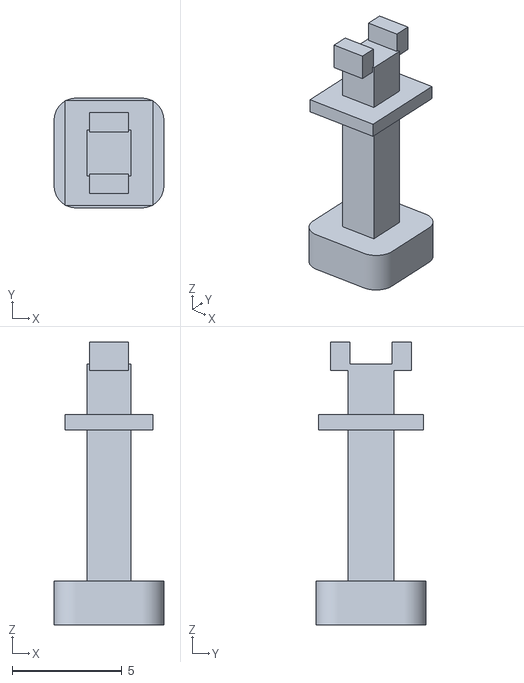
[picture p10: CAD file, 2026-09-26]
printing/stl/08_power_slider_spare.stl
5.00 x 5.00 x 12.9

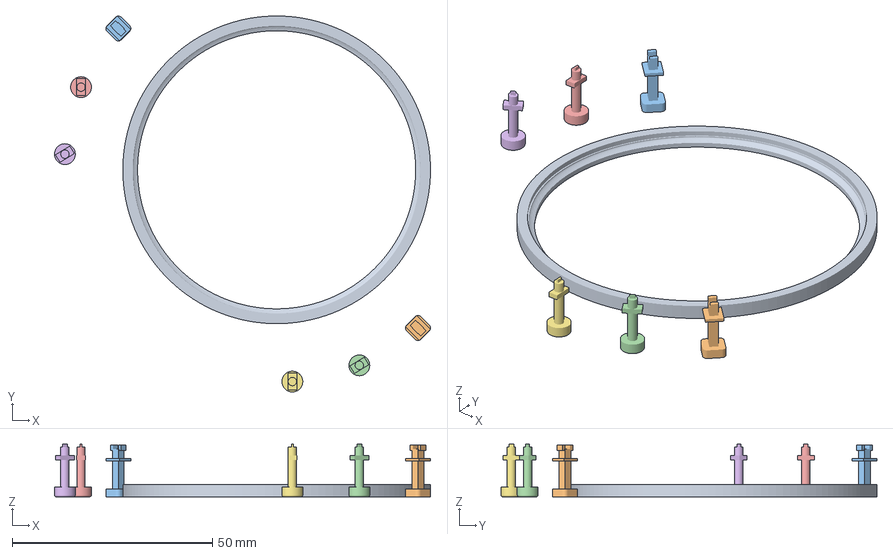
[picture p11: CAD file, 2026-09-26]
printing/plates/01_B_Proba_i_przyciski_P2S_PLA.3mf
93.8 x 93.8 x 13.1 mm
00_B_fit_ring_71p8.stl
08_power_slider.stl
08_power_slider_spare.stl
06_button_BOOT.stl
07_button_RESET.stl
06_button_BOOT_spare.stl
07_button_RESET_spare.stl

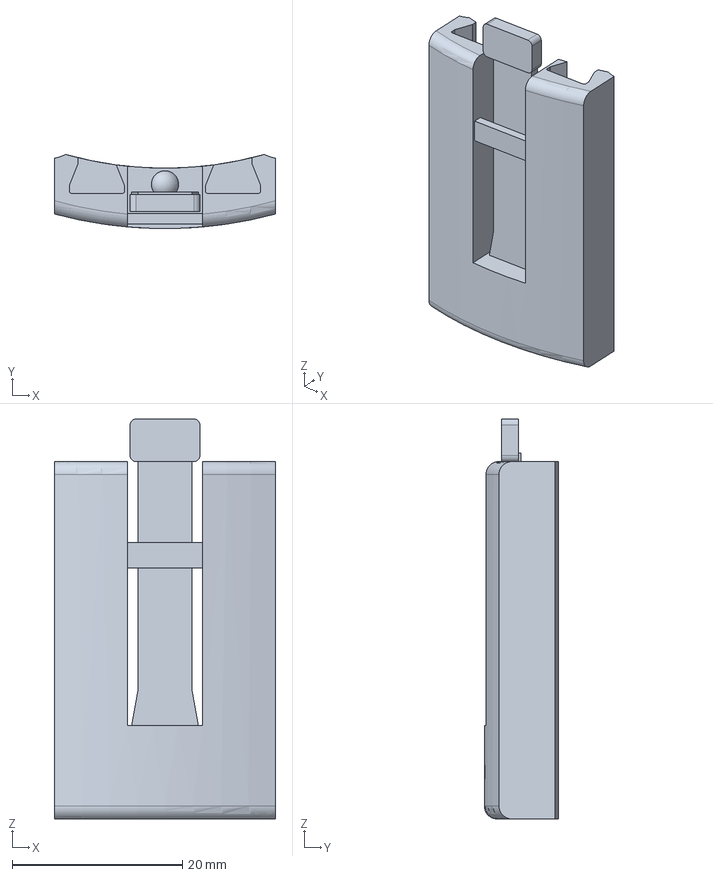
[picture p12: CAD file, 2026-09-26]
printing/step/D1_receiver_interface_TEMPLATE.step
26.0 x 8.72 x 47.0 mm

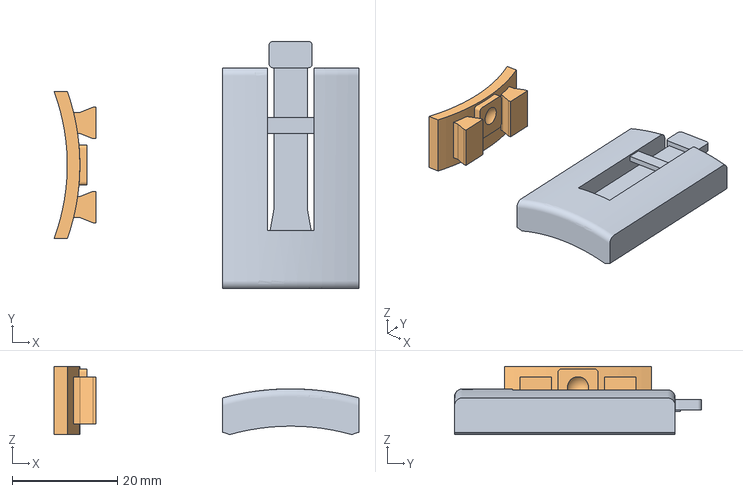
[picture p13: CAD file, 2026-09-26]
printing/plates/04_D1_Proba_mocowania_P2S_PLA.3mf
58.0 x 47.0 x 13.0 mm
00_D1_receiver_coupon.stl
00_D1_body_coupon.stl

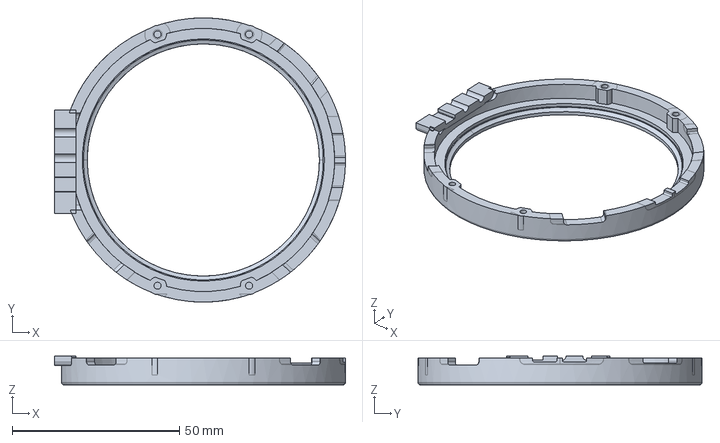
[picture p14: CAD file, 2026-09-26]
printing/step/01_crab_front.step
87.0 x 85.0 x 8.65 mm

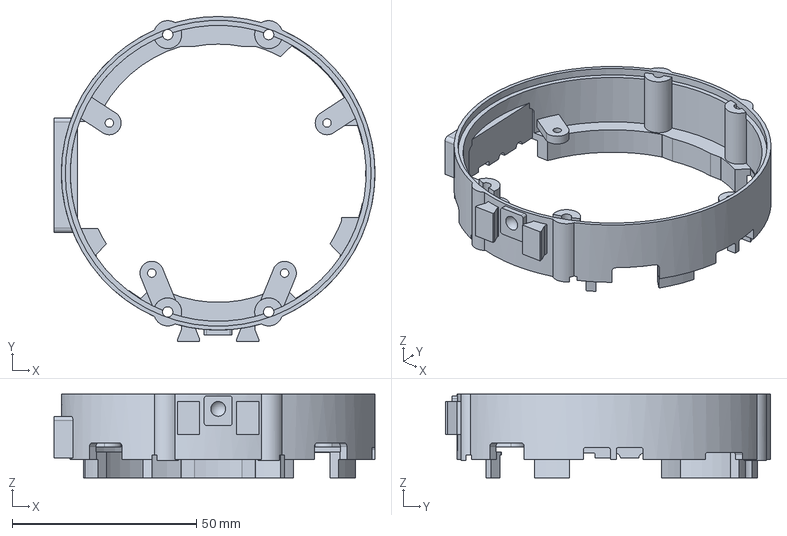
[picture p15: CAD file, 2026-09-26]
printing/step/02_crab_rear.step
87.0 x 88.1 x 22.7 mm

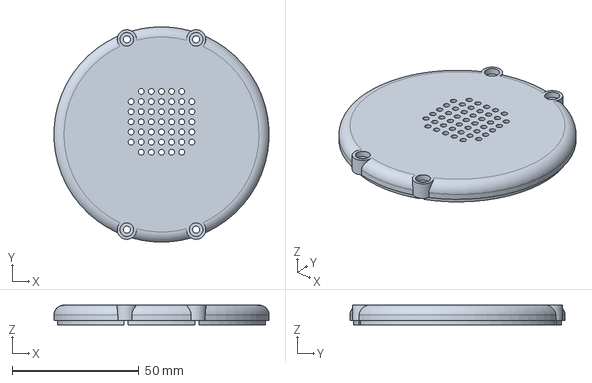
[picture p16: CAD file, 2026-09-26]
printing/step/09_rear_service_cover.step
84.9 x 85.0 x 7.85 mm

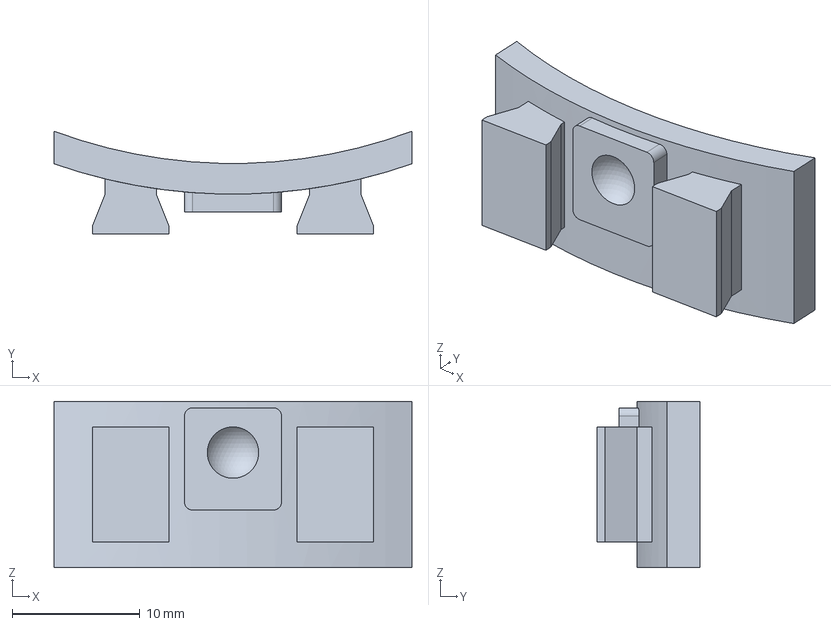
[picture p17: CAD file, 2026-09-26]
printing/step/00_D1_body_coupon.step
28.0 x 8.02 x 13.0 mm

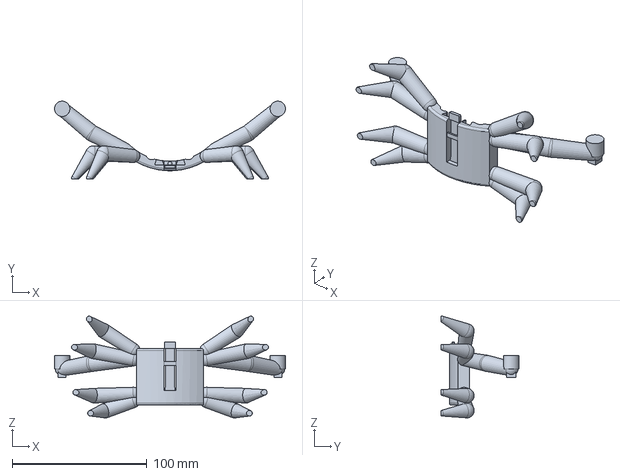
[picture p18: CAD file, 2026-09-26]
printing/step/03_crab_base.step
171.4 x 57.7 x 75.6 mm

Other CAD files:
printing/stl/06_button_BOOT_spare.stl
printing/stl/07_button_RESET_spare.stl
printing/step/06_button_BOOT.step
printing/step/05_claw_R.step
printing/step/00_B_fit_ring_71p8.step
printing/step/08_power_slider.step
printing/stl/00_B_fit_ring_71p8.stl
printing/stl/00_D1_body_coupon.stl
printing/stl/00_D1_receiver_coupon.stl
printing/stl/01_crab_front.stl
printing/stl/02_crab_rear.stl
printing/stl/03_crab_base.stl
printing/stl/04_claw_L.stl
printing/stl/05_claw_R.stl
printing/stl/06_button_BOOT.stl
printing/stl/07_button_RESET.stl
printing/stl/09_rear_service_cover.stl

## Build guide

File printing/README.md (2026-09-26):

# Printing Pinchy

[Polska instrukcja](README_PL.md) · [STL parts](stl/) · [Editable STEP parts](step/) · [Assembly](../docs/ASSEMBLY.md)

Current mechanical revision: **B / D1**, previously designated C03B. Designed for **Waveshare ESP32-S3-Touch-LCD-2.1B / SKU 30697**, nominal Ø71.8 mm glass. The flat 28169 version is not interchangeable.

Open the 3MF files with **File → Open Project** in Bambu Studio. The saved profiles target **Bambu Lab P2S, 0.4 mm nozzle, Generic PLA, Textured PEI**, at **100% scale**. One raspberry filament is also used for supports; no AMS is needed. The display color is `#C74565`; use a physical spool matching the desired color.

| Plate | Contents | Layer | Slicer estimate |
|---|---|---:|---|
| [01 — screen fit and controls](plates/01_B_Proba_i_przyciski_P2S_PLA.3mf) | Profiled glass coupon, BOOT/RESET/slider and spares | 0.12 mm | 58 min / 4.41 g |
| [02 — enclosure](plates/02_B_Obudowa_P2S_PLA.3mf) | Front, central shell with four M2 supports and removable cover | 0.16 mm | 3 h 41 min / 50.10 g |
| [03 — D1 base and claws](plates/03_B_Nogi_i_szczypce_P2S_PLA.3mf) | Complete legs and both claws | 0.16 mm | 6 h 50 min / 85.93 g |
| [04 — D1 interface coupon](plates/04_D1_Proba_mocowania_P2S_PLA.3mf) | Both mating interface samples | 0.16 mm | 48 min / 7.92 g |

Total including coupons and spare controls: about **12 h 17 min / 148.36 g**. Estimates include slicer assumptions; allow extra material for tests. Saved temperatures are 220°C nozzle / 55°C bed, with a 10 mm³/s flow limit. Confirm printer, plate and filament in Bambu Studio and reslice after changing settings.

Print **04 and 01 first**. Test the D1 slide/click/release and the actual screen's glass support before committing to the full set. The screen must stop on the shaped front lip; it must not fall through. Current glass pocket Ø72.4 mm, visible opening Ø69.4 mm. Do not scale the entire model to fix an interface tolerance.

The nine main parts are `01_crab_front`, `02_crab_rear`, `03_crab_base`, `04_claw_L`, `05_claw_R`, `06_button_BOOT`, `07_button_RESET`, `08_power_slider`, and `09_rear_service_cover`. Original internal part identifiers are retained so STEP, STL and 3MF names agree. `00_*` files are coupons and `*_spare` are additional controls.

STL files are in print orientation and millimetres. STEP files are in millimetres; preserve the assembly coordinate system when editing the D1 receiver template. The web preview is a simplified viewing mesh and must not be used as the print source.

The current shell and base are a matching D1 pair. USB clearance comes from spacing complete leg pairs. The assumed USB plug body is no larger than 12 × 6 mm and 15 mm long; actual cable molding must be checked.

CAD and slicer checks exist, but physical fit, spring retention and repeated-use performance of this exact revision remain unverified. Audio/battery holders and the completed harness are outside the current printable set; see [build status](../docs/BUILD_STATUS.md).

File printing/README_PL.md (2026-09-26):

# Pinchy — druk dla Waveshare 30697 / 2.1B

Ta paczka jest przygotowana dla **Bambu Lab P2S, dysza 0,4 mm, różowy Generic PLA**, stół Textured PEI. Otwieraj pliki jako projekty Bambu Studio i zachowaj skalę 100%. Podgląd koloru: `#C74565`.

W końcowej wersji panel przycisków ma zamknięte prześwity u góry i dołu. Ekran w złożeniu jest pionowy, pod kątem 90° do podłogi.

**Najpierw sprawdź próbnik.** Wersja B ma nominalnie szkło Ø71,8 mm. Nowe gniazdo ma Ø72,4 mm, a otwór zatrzymujący ekran Ø69,4 mm. Próbnik posiada profil rzeczywistego podparcia szkła 2.5D. Ekran ma oprzeć się na rancie, nie przejść przez cały otwór. Sprawdź z miękką podkładką, bez wciskania na siłę.

| Płyta | Zawartość | Szacowany czas / PLA |
|---|---|---|
| `01_B_Proba_i_przyciski_P2S_PLA.3mf` | Próbnik, przyciski i ich zapas | 58 min / 4,41 g |
| `02_B_Obudowa_P2S_PLA.3mf` | **Nowy przód, korpus z M2 i pokrywa** | 3 h 41 min / 50,10 g |
| `03_B_Nogi_i_szczypce_P2S_PLA.3mf` | Podstawa z nogami i dwa szczypce | 6 h 50 min / 85,93 g |
| `04_D1_Proba_mocowania_P2S_PLA.3mf` | Dwie połówki próbnika wymiennej podstawy | 48 min / 7,92 g |

Jeśli masz poprzedni C03B, **wymień korpus 02 i podstawę 03** na zgodną parę D1. Przód B, pokrywa B, szczypce i nakładki są bez zmian. Przechodząc z C01 wymień także przód i dodaj pokrywę `09_rear_service_cover`. Poprzedni front z otworem Ø73 mm był do innego wariantu Waveshare. Z płyty 1 można usunąć przyciski, jeżeli potrzebujesz tylko nowego próbnika.

Ustawienia: 220°C dysza / 55°C stół, jedna PLA także na podpory, warstwa 0,12 mm dla próbnika/przycisków i 0,16 mm dla reszty. AMS nie jest wymagany. Geometria ma skalę 1:1. Nie zmniejszaj całego modelu, aby dopasować szkło — zmieniłoby to otwory, gwinty i pozycje przycisków.

Po próbie załóż cienkie miękkie podparcie na przedni profil; przewidziano około 0,2 mm luzu osiowego. Tylny docisk ma nominalnie około 0,4 mm na miękkie paski. Sprawdź równomierne ułożenie szkła, swobodny powrót przycisków i działanie dotyku przed ostatecznym skręceniem. Trzy części pancerza łączą 4 wkręty do tworzywa Ø2,5 × 25 mm, łby do Ø4,8 mm. Nie dociskaj szkła sztywnym tworzywem ani nadmierną siłą.

Nowe cztery podpory przykręca się do fabrycznych nakrętek płytki śrubami **M2 × 5 mm**, łeb maks. Ø3,8 × 2 mm. Podpory mają 2,4 mm grubości, otwory Ø2,3 mm; nominalne zagłębienie w gwint to 2,6 mm. Sprawdź użyteczną głębokość gwintu na swoim egzemplarzu. To osobne śruby od wkrętów Ø2,5 × 25 łączących pancerz.

Montaż: przednia ramka na miękkiej powierzchni → cały moduł B i podkładki → przyciski oraz środkowy korpus → cztery śruby M2 od otwartego tyłu → ewentualne dodatki → pokrywa i cztery długie wkręty. Przed włożeniem dodatków zapewniono dostęp śrubokręta Ø4,4 mm. Śruby dokręcaj lekko; nie wyginaj PCB ani szkła.

Mniejsze otwory: USB-C 12,8 × 6,8 mm, dwa złącza rozszerzeń po 7,3 × 4,6 mm, microSD 14,4 × 3,6 mm. USB-C przewidziano dla plastikowej końcówki do 12 × 6 mm i długości do 15 mm, z luzem 0,4 mm na stronę. Sprawdź swój kabel przed drukiem. Nowe pełne nogi mają odstęp między parami: obie drogi USB są wolne, z minimalnym nominalnym odstępem 2,07 mm od przyjętej wtyczki. Długi ruch wtyczek rozszerzeń nadal może wymagać zdjęcia szczypca. microSD ma wąską szczelinę; serwis palcem po zdjęciu pokrywy.

W folderze `stl` znajdują się osobne części do druku i zapasowe przyciski. Kupowane elementy elektroniczne nie są częścią tych plików. Dodatkowy mikrofon, głośnik, wzmacniacz i bateria mieszczą się gabarytowo w osobnym złożeniu CAD. Przygotowano diagram połączeń i koncepcję tras w pełnej paczce projektu; docelowe mocowania dodatków, otwór mikrofonu, pełna wiązka i kanały do druku pozostają do opracowania.

Wykonano kontrolę CAD względem oficjalnego modułu B oraz kontrolę ścieżek w 3MF. **Fizyczna przymiarka tej wersji pozostaje do wykonania.** Raporty kontroli są w paczce; kompletna dokumentacja i edytowalne modele znajdują się w osobnej paczce projektu C03B.

## Wymienna podstawa D1

Najpierw drukuj płytę 04 i usuń podpory z obu rowków oraz spod sprężystego języczka. Sprawdź swobodne prowadzenie i łagodny klik. Podstawa wsuwa się od strony ekranu ku tyłowi. Żeby ją zdjąć, podeprzyj korpus, naciśnij tylną łopatkę od spodu w dół, od obudowy, i wysuń podstawę ku ekranowi. Niczego nie rozkręcasz. Stare części 02 i 03 nie mają D1.

[Pełna instrukcja i wymiary D1](../docs/D1_INTERFACE_PL.md). Luz profilu rowków wynosi 0,25 mm; siła kliku, trwałość sprężyny PLA i nośność wymagają fizycznej próby. Nie skaluj całego modelu dla dopasowania zatrzasku. Komplet czterech płyt: około 12 h 17 min / 148,36 g według slicera.

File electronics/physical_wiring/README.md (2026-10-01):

# Pinchy photo wiring explorer — 1 October 2026

The `../03_physical_connections.*` files show physical modules, pads and proposed connections. The English interactive page uses the same charcoal background, raspberry accents, navigation and sidebar layout as the 3D explorer. The two pages link to each other. The drawings, connection table and PDF / SVG downloads are also in English.

## Files and controls

- `page.html`: self-contained page template, styles and interaction code.
- `build.py`: generates the English HTML, SVG, CSV and `connections.json`; requires Python 3 and Pillow. If the repository has a `site/` directory, it also updates `site/wiring/index.html` and the downloadable SVG, with the correct relative link back to the model.
- `assets/`: source photographs and the manufacturer rendering, embedded in the SVG and HTML.
- PDF: one landscape A3 page. PNG: 4800 × 3420 pixels. These are exported from the generated SVG using Sharp and ReportLab, and must be refreshed after changing the drawing. Copy the PDF to `site/wiring/` too.

Choose a signal from the sidebar or click a wire to highlight that signal. **Show all** resets the selection. **Fit view** fits the full drawing inside the viewport; the percentage is relative to that fitted size. Zoom reaches 400%; scroll to explore the enlarged sheet. The table and source references remain available below the workspace.

The root SVG alone scales with its container. Nested image viewports keep their documented dimensions so that the photographed pads remain aligned with the wire endpoints.

## Hardware variant

- Waveshare ESP32-S3-Touch-LCD-2.1B / 30697: a rear PCB reference photo from the 2.1 product page and the shared published schematic. Check the actual board revision before soldering.
- Adafruit SPH0645 #3421 microphone, sound-port side.
- DFRobot DFR0954 MAX98357A: assumed from the shopping list, not separately confirmed by the owner. The pad layout is for DFR0954, not Adafruit #3006.
- Kamami 560816 speaker, 8 Ω / 1 W.
- Confirmed battery: Akyga AKY0107 / LP503759, 3.7 V / 1350 mAh, PCM, factory JST 2.54 mm connector.

The 3D explorer still contains earlier Adafruit reference geometry. Linking the two pages does not validate the new components' mechanical fit.

## Validation limits

This remains a bench-test proposal. J9 pin numbers come from the manufacturer schematic; the J9 and J1 expansions are not connector-face views. The physical VCC solder point has not been identified. Charging must be adapted and VCC, current and I²S behavior measured before validating the prototype. Dashed power connections mark these conditions. The gray leader to the factory battery plug is an annotation, not an electrical wire.

The 100 kΩ resistor connects DOUT to GND, not in series with DOUT and not to the crossing BCLK line. Only dots mark electrical junctions.

Browser checks cover desktop and phone layouts, navigation in both directions, sidebar and wire selection, zoom, reset and table access. The 3D model/renderer and the SVG wire geometry are unchanged by this interface update. No electrical measurements have been performed.

## Sources

- [Waveshare documentation](https://docs.waveshare.com/ESP32-S3-Touch-LCD-2.1) and [schematic](https://files.waveshare.com/wiki/ESP32-S3-Touch-LCD-2.1/ESP32-S3-Touch-LCD-2.1_schematic_diagram.pdf).
- [Adafruit #3421 pinout](https://learn.adafruit.com/adafruit-i2s-mems-microphone-breakout/pinouts) and [Knowles SPH0645 datasheet, p. 7](https://cdn-shop.adafruit.com/product-files/3421/i2S%20Datasheet.PDF#page=7).
- [DFRobot DFR0954 module and pinout](https://wiki.dfrobot.com/dfr0954/).
- [Akyga AKY0107 datasheet](https://www.tme.eu/Document/d09d785c980e096e8a2305b0492fc05e/AKY0107.pdf).
- Battery and speaker photos: Kamami product pages 1202750 and 560816, linked in the HTML. Other photos / rendering: Waveshare, Adafruit and DFRobot. Rights remain with their owners.

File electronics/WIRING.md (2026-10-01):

# Pinchy — proposed wiring and cable routing

**New photo diagram (1 October 2026):** [interactive view](https://pablo-mano.github.io/Pinchy/wiring/) · [PNG](03_physical_connections.png) · [PDF A3](03_physical_connections.pdf) · [SVG](03_physical_connections.svg) · [source and assumptions](physical_wiring/README.md). This variant uses the confirmed Akyga AKY0107 / LP503759 1350 mAh pack, the procurement-list DFRobot DFR0954 amplifier (not separately confirmed) and the Kamami 560816 speaker. Dashed power connections require verification. The earlier diagrams and battery-specific details below describe the Adafruit reference parts.

[Polski: pełna instrukcja](WIRING_PL.md) · [BOM](BOM.md) · [Netlist CSV](connections.csv)

This is a **bench-test proposal**, not an electrically validated assembly. The connector numbers below come from the published Waveshare schematic; the drawing is not a connector-face view. Establish pin 1 and continuity on the actual **30697 / 2.1B** board.

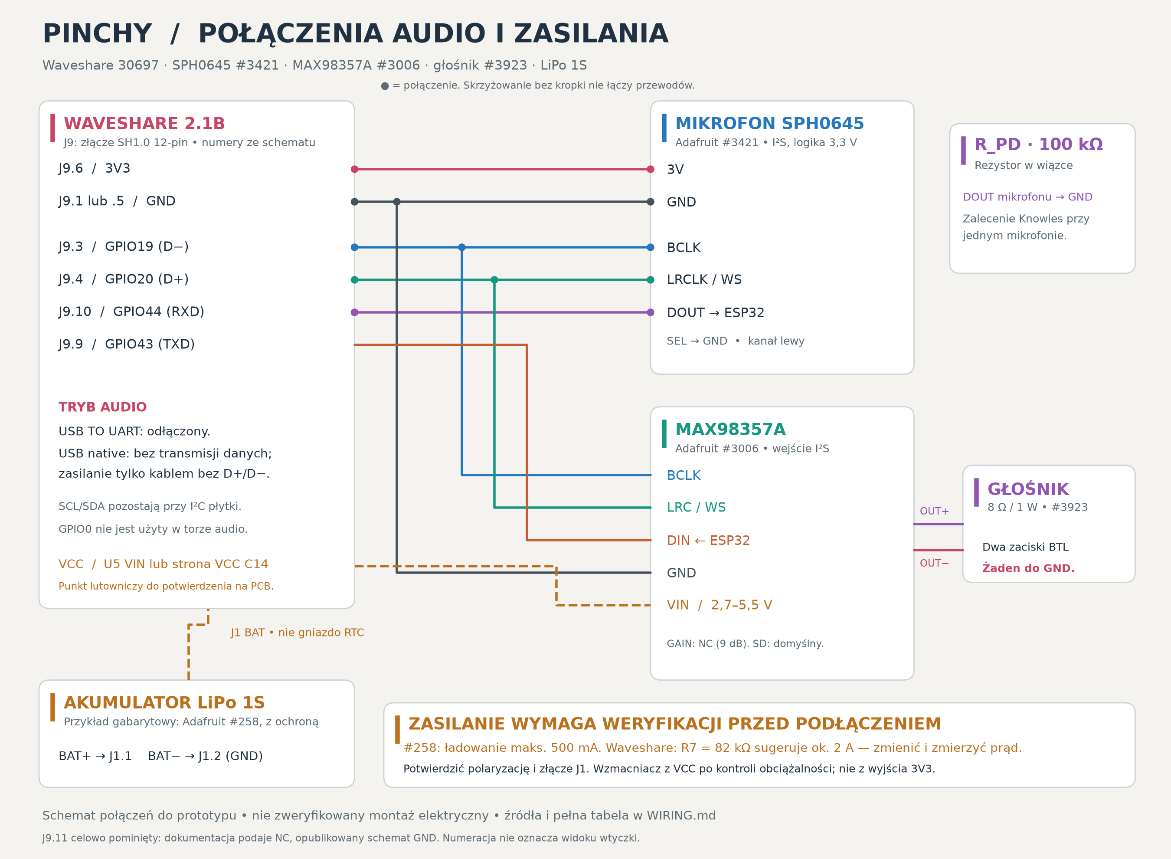
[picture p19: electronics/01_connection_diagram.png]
Pinchy connection diagram


[Vector diagram](01_connection_diagram.svg) · [Routing SVG](02_cable_routing_plan.svg) · [3D routing study](Pinchy_cable_plan.glb) · [Route coordinates](cable_routes.json)

| From | To | Function / condition |
|---|---|---|
| J9.6 / 3V3 | SPH0645 3V | Microphone power |
| J9.1 or J9.5 / GND | Microphone GND and amplifier GND | Common ground; route amplifier return with its power lead |
| J9.3 / GPIO19 / D− | Microphone BCLK + amplifier BCLK | Shared bit clock; conflicts with native USB |
| J9.4 / GPIO20 / D+ | Microphone LRCLK + amplifier LRC | Shared word clock; conflicts with native USB |
| Microphone DOUT | J9.10 / GPIO44 / RXD | Audio input; board UART switching must be verified |
| J9.9 / GPIO43 / TXD | Amplifier DIN | Audio output; board UART switching must be verified |
| Microphone SEL | Microphone GND | Select left channel |
| Microphone DOUT | 100 kΩ resistor to GND | Pull-down for the single-microphone arrangement |
| Verified VCC net at U5 VIN or VCC side of C14 | MAX98357 VIN | Physical solder point and current capability not yet verified |
| MAX98357 OUT+ and OUT− | Speaker terminals | BTL output: **neither terminal goes to ground** |
| Protected LiPo BAT+ / BAT− | J1.1 BAT / J1.2 GND | Only after charge-current, connector and polarity verification |

J9.11 is deliberately unused: the documentation and an older schematic disagree about NC versus GND. J9 is SH1.0 12-pin; the main battery connector is separately described as MX1.25 2-pin. The RTC battery socket is not the device supply.

## USB, UART and I²S

GPIO19/20 are native USB data pins. GPIO43/44 share the UART path and hardware switching. In the proposed audio mode, USB TO UART must be disconnected and firmware must release these pins. Verify the multiplexer and continuity on the physical board before wiring the full harness.

A native-USB power-only connection must leave device-side D+ and D− **individually isolated, including from one another**. Generic charge-only cables/data blockers may short them. A programming data cable is not automatically suitable for audio-mode power. Stop audio and use a service configuration for programming.

Preliminary bench format: Philips I²S, 48 kHz, two 32-bit slots, BCLK 3.072 MHz. Confirm SPH0645 data alignment before processing audio. The microphone requires a BCLK/WS ratio of 64. No MCLK is needed. MAX98357 GAIN is left open for the module default; start at low volume, respect the speaker's 1 W rating and send the same speech to both slots.

## Power conditions still to resolve

The amplifier requires a verified supply within its module rating, with common ground, sufficient current and suitable decoupling. The proposed VCC tap is not a confirmed physical solder pad. Measure behavior on USB, battery and both power-switch positions; do not assume USB VBUS exists on battery or load the board's 3V3 rail with the amplifier without a power budget.

The Adafruit #258 reference pack permits at most **500 mA charging**. The published board schematic's ETA6098 and R7=82 kΩ suggest roughly **2 A**; this is a schematic inference, not a measurement of this board. Resolve and measure the charger setting before connecting that pack. No substitute resistor or second parallel charger is specified here. A battery's capacity or discharge-current rating does not establish its allowed charge current.

Match the actual main-battery connector and verify BAT+/GND by measurement. The Adafruit JST-PH lead is not automatically compatible with the Waveshare connector.

## Routing

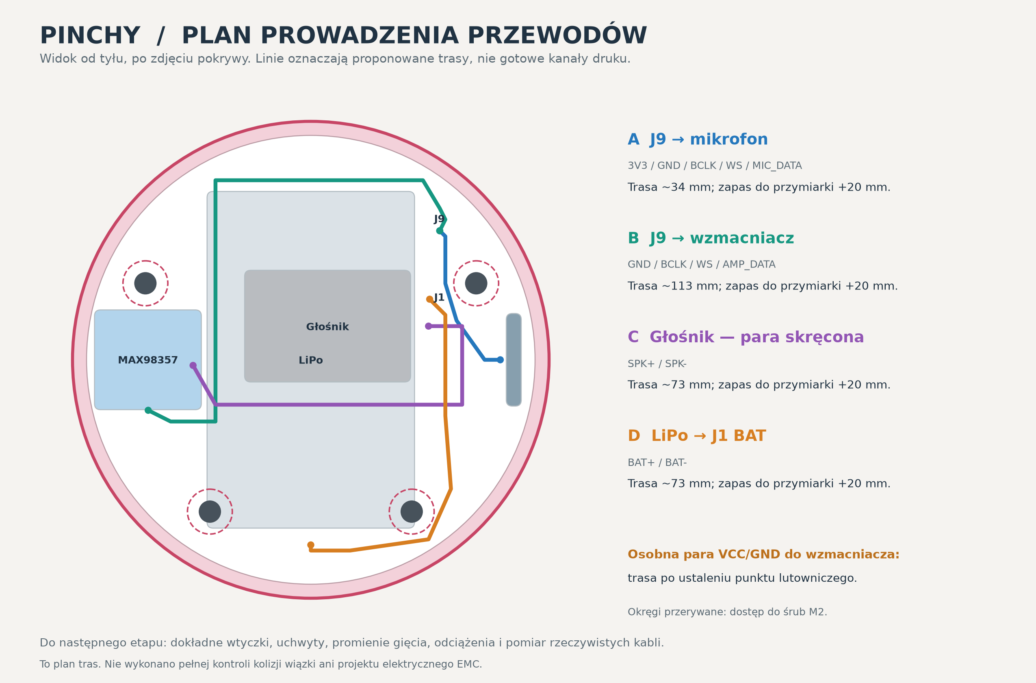
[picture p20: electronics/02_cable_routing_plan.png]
Cable routing study


- **A, microphone:** from J9 along the upper side to the microphone; keep away from speaker and amplifier power wiring.
- **B, amplifier data:** above the battery toward the amplifier. The narrow gap beside the battery is not assumed to fit an entire bundle.
- **C, speaker:** a short twisted OUT+/OUT− pair around the speaker edge, away from the microphone acoustic port.
- **D, battery:** along the side to J1, away from M2 heads and the cover seam, with strain relief.
- **Amplifier VCC/GND:** a separate pair; final route awaits the verified VCC connection point.

Nominal route centerlines are about 34 / 113 / 73 / 73 mm for A/B/C/D. These are not finished cut lengths. Begin with approximately 20 mm service allowance, then fit the actual connectors and bends. Signal-wire target is flexible 30 AWG with insulation up to Ø0.7 mm; power/speaker wire 26–28 AWG remains subject to current, voltage-drop and fit checks.

Final connectors, bend radii, microphone channel, audio holders, battery restraint, antenna clearance and the whole-harness collision check are unfinished. The four printed M2 supports secure the Waveshare board, not the extra audio modules.

## Source references

- [Waveshare documentation](https://docs.waveshare.com/ESP32-S3-Touch-LCD-2.1) and [published schematic](https://files.waveshare.com/wiki/ESP32-S3-Touch-LCD-2.1/ESP32-S3-Touch-LCD-2.1_schematic_diagram.pdf).
- [SPH0645 pinout](https://learn.adafruit.com/adafruit-i2s-mems-microphone-breakout/pinouts) and [Knowles datasheet](https://cdn-shop.adafruit.com/product-files/3421/i2S%20Datasheet.PDF).
- [MAX98357A pinout](https://learn.adafruit.com/adafruit-max98357-i2s-class-d-mono-amp/pinouts).
- [Adafruit battery #258](https://www.adafruit.com/product/258) and [ETA6098 datasheet](https://www.eta-semi.com/wp-content/uploads/2022/03/ETA6098_V1.1.pdf).
- [ESP32-S3 I²S](https://docs.espressif.com/projects/esp-idf/en/latest/esp32s3/api-reference/peripherals/i2s.html).

Electrical plan originally documented on 25 September 2026; this package changes its project name and links, not its validation status.

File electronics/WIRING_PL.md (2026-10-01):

# Pinchy — diagram połączeń i plan wiązki

**Nowy diagram fotograficzny (01.10.2026):** [wersja interaktywna](https://pablo-mano.github.io/Pinchy/wiring/) · [PNG](03_physical_connections.png) · [PDF A3](03_physical_connections.pdf) · [SVG](03_physical_connections.svg) · [źródła i założenia](physical_wiring/README.md). Uwzględnia potwierdzoną baterię Akyga AKY0107 / LP503759 1350 mAh, wzmacniacz DFRobot DFR0954 przyjęty z listy zakupowej i głośnik Kamami 560816. Przerywane połączenia zasilania wymagają weryfikacji. Poniższy wcześniejszy opis dotyczy wariantu z referencyjnymi częściami Adafruit.

**Wariant do zbudowania i sprawdzenia na stole, nie potwierdzony montaż elektryczny.** Dotyczy Waveshare ESP32-S3-Touch-LCD-2.1B / 30697, mikrofonu Adafruit SPH0645 #3421, wzmacniacza MAX98357A #3006, głośnika 8 Ω / 1 W #3923 i chronionego LiPo 1S. Rysunki są schematami połączeń, nie widokiem pinów wtyczki; stronę pin 1 należy ustalić na fizycznej płytce.

Diagram połączeń

Wersja wektorowa: [SVG](01_connection_diagram.svg). Tabela maszynowa: [connections.csv](connections.csv).

## Przypisanie sygnałów

Numery J9 pochodzą z opublikowanego schematu Waveshare. Funkcje GPIO potwierdza bieżąca dokumentacja wariantów 2.1 i 2.1B. J9 ma opis SH1.0 12P; nie utożsamiaj go ze złączem akumulatora o rastrze 1,25 mm.

| Z płytki / elementu | Do | Funkcja |
|---|---|---|
| J9.6 — 3V3 | Mikrofon 3V | Zasilanie mikrofonu |
| J9.1 lub J9.5 — GND | Mikrofon GND i wzmacniacz GND | Wspólna masa; przewód powrotny wzmacniacza poprowadzić z jego zasilaniem |
| J9.3 — D− / GPIO19 | Mikrofon BCLK oraz wzmacniacz BCLK | Wspólny zegar bitowy |
| J9.4 — D+ / GPIO20 | Mikrofon LRCLK/WS oraz wzmacniacz LRC | Wspólny zegar próbek |
| Mikrofon DOUT | J9.10 — RXD / GPIO44 | Audio z mikrofonu do ESP32 |
| J9.9 — TXD / GPIO43 | Wzmacniacz DIN | Audio z ESP32 do wzmacniacza |
| Mikrofon SEL | Mikrofon GND | Kanał lewy |
| Mikrofon DOUT | 100 kΩ → GND | Pull-down zalecany przez Knowles przy jednym mikrofonie; uwzględnić w wiązce. Źródłowe PCB #3421 nie zawiera tego rezystora na DOUT. |
| VCC na Waveshare, sieć U5.VIN / strona VCC C14 | MAX98357 VIN | **Warunkowo:** po identyfikacji fizycznego punktu, pomiarze napięcia i kontroli obciążalności |
| MAX98357 OUT+ i OUT− | Dwa przewody głośnika | Wyjście mostkowe BTL; żaden zacisk głośnika nie jest GND |
| Chroniony LiPo BAT+ | J1.1 BAT | **Dopiero po dostosowaniu ładowania i potwierdzeniu polaryzacji** |
| Chroniony LiPo BAT− | J1.2 GND | Złącze głównego pakietu, nie podtrzymania RTC |

GAIN wzmacniacza pozostaje niepodłączony (domyślnie 9 dB); SD/MODE pozostaje w konfiguracji modułu. Dla mowy wysyłać ten sam sygnał do obu kanałów ramki I²S. Poziom wyjściowy należy ograniczyć do możliwości głośnika 1 W i rozpocząć test od małej głośności. Układ nie potrzebuje MCLK.

**J9.11 nie jest użyty.** Strona dokumentacji opisuje go jako NC, starszy opublikowany schemat jako GND. Tę rozbieżność odnotowano; nie oparto na nim żadnego połączenia.

## Tryb audio a porty USB

GPIO19/20 współdzielą funkcję native USB. GPIO43/44 współdzielą UART i przełącznik FSUSB42. Dokumentacja producenta mówi, że podłączenie USB TO UART odcina zewnętrzny UART.

- W trybie audio USB TO UART musi być odłączony; firmware zwalnia UART i USB z tych GPIO.
- Gniazdo native USB może być rozpatrywane do samego zasilania z kablem bez linii D+/D− albo odpowiednim separatorem danych. Nie łączyć aktywnego hosta USB z liniami używanymi jako BCLK/WS.
- Do programowania zatrzymać audio i przejść w tryb serwisowy. Po zaprogramowaniu odłączyć USB TO UART i uruchomić tryb głosowy. W docelowym urządzeniu aktualizacje OTA ograniczą potrzebę przepinania.
- I²C GPIO7/15 pozostaje dla urządzeń na płytce i nie jest wykorzystane do I²S. GPIO0 nie jest potrzebne.

Przed zrobieniem całej wiązki należy potwierdzić ciągłość GPIO19/20 i przebieg połączeń GPIO43/44 przez multiplekser na posiadanej rewizji. Propozycja wykorzystuje wyprowadzenia wymienione przez Waveshare; nie wykonano jeszcze testu I²S na tym egzemplarzu.

Wstępne ustawienia do testu: Philips I²S, 48 kHz, 2 sloty po 32 bity, BCLK 3,072 MHz. Mikrofon SPH0645 wymaga BCLK/WS = 64; jego 18-bitowe dane należy poprawnie wydobyć z 24-bitowego słowa. Standardowy sterownik ESP32-S3 obsługuje RX/TX współdzielące BCLK i WS. Działanie rozpoznawania mowy, format TTS i resampling to osobny etap firmware.

## Zasilanie i bateria

VIN wzmacniacza wymaga 2,7–5,5 V. Sieć VCC na schemacie jest wejściem stabilizatora U5 i kondensatorów C14/C17, zasilanym przez układ wyboru USB/bateria. **Nie zaznaczono niezweryfikowanego punktu lutowania na zdjęciu PCB.** Najpierw trzeba odnaleźć odpowiednią stronę C14 lub wejście U5, zmierzyć napięcie przy USB, baterii i obu pozycjach wyłącznika oraz sprawdzić obciążenie. Zasilanie wzmacniacza z wyjścia 3V3 nie zostało przyjęte; LDO obsługuje także ESP32 i ekran.

Adafruit #258 dopuszcza ładowanie najwyżej 500 mA. Schemat Waveshare pokazuje ETA6098 i R7=82 kΩ, odpowiadające około 2 A według tabeli producenta układu. To wniosek ze schematu, nie pomiar płytki. **Nie podłączać #258 do ładowania bez obniżenia i sprawdzenia prądu.** Rezystor zamienny i ewentualne odsprzęganie wzmacniacza dobieramy po weryfikacji rzeczywistej rewizji. Nie dodawać drugiej ładowarki równolegle.

JST-PH pakietu #258 nie pasuje automatycznie do gniazda głównego akumulatora Waveshare opisanego jako MX1.25 2PIN. Wymagana pasująca wiązka i kontrola BAT+/GND miernikiem; kolory przewodów nie są dowodem polaryzacji. Złącze RTC nie służy do zasilania urządzenia.

## Plan ułożenia przewodów

Plan tras

[SVG tras](02_cable_routing_plan.svg), [współrzędne planu](cable_routes.json) oraz [podgląd 3D GLB](Pinchy_cable_plan.glb). W projekcie Blender trasy są osobną, domyślnie ukrytą kolekcją referencyjną. Linie wskazują miejsca do zajęcia przez wiązkę; nie są odwzorowaniem poszczególnych przewodów, kompletnych wtyczek ani gotowych kanałów do druku.

- **A — mikrofon:** od J9 górną lewą stroną w układzie CAD, następnie przy boku do padów mikrofonu. Oddzielić od przewodów głośnika i zasilania wzmacniacza.
- **B — dane wzmacniacza:** wzdłuż górnej krawędzi baterii, później nad pakietem po stronie wzmacniacza. W wąskiej szczelinie między boczną krawędzią baterii a PCB wzmacniacza nie ma miejsca na całą grubą wiązkę, dlatego proponowana trasa biegnie wyżej w osi Z.
- **C — głośnik:** skręcona para OUT+/OUT−, możliwie krótka, prowadzona wokół dolnej krawędzi głośnika. Nie prowadzić tuż przy porcie mikrofonu ani równolegle do jego wiązki na całej długości.
- **D — bateria:** od dolnego wyjścia pakietu, bokiem do J1. Nie przeprowadzać pod łbami M2 ani przez płaszczyznę łączenia pokrywy. Dodać odciążenie przy pakiecie i konektorze.
- **VCC/GND do wzmacniacza:** osobna para z lokalnym odsprzęganiem według potrzeb testu. Trasa pozostaje nieustalona, dopóki nie zostanie potwierdzone miejsce pobrania VCC.

Wstępny dobór przewodów: sygnały elastyczna linka 30 AWG z izolacją do Ø0,7 mm; zasilanie i głośnik 26–28 AWG po sprawdzeniu prądu, spadku napięcia i średnicy izolacji. Przy pierwszej przymiarce zostawić około 20 mm zapasu, a potem skrócić. W JSON długości są obliczone po łamanych i służą tylko do planowania. Przyjęty promień gięcia do kolejnego etapu: co najmniej 3 mm, do potwierdzenia dla użytego przewodu.

Do wykonania przed projektowaniem kanałów: dopasowanie rzeczywistych wtyczek J9/J1, sprawdzenie ich wsuwania w obecnym korpusie, fizyczne uchwyty audio i pakietu, promienie łuków, zakaz prowadzenia nad anteną, dostęp do śrub i portów oraz pełna kontrola kolizji wiązki. Cztery nowe mocowania dotyczą **płytki Waveshare**; nie są uchwytami baterii i audio.

## Źródła

- [Waveshare — mapowanie SKU, GPIO, złącza i multiplekser](https://docs.waveshare.com/ESP32-S3-Touch-LCD-2.1).
- [Waveshare — schemat płytki](https://files.waveshare.com/wiki/ESP32-S3-Touch-LCD-2.1/ESP32-S3-Touch-LCD-2.1_schematic_diagram.pdf), lokalna kopia `research/waveshare_21/board_schematic.pdf`.
- [Adafruit — SPH0645 pinout](https://learn.adafruit.com/adafruit-i2s-mems-microphone-breakout/pinouts) i [Knowles — datasheet](https://cdn-shop.adafruit.com/product-files/3421/i2S%20Datasheet.PDF).
- [Adafruit — MAX98357A pinout, zasilanie i wyjście BTL](https://learn.adafruit.com/adafruit-max98357-i2s-class-d-mono-amp/pinouts).
- [Espressif — I²S ESP32-S3](https://docs.espressif.com/projects/esp-idf/en/latest/esp32s3/api-reference/peripherals/i2s.html).
- [Adafruit — #258 i prąd ładowania](https://www.adafruit.com/product/258); [ETA6098 — tabela ISET](https://www.eta-semi.com/wp-content/uploads/2022/03/ETA6098_V1.1.pdf).

Stan: 25.09.2026. Diagram, netlista i koncepcja tras; jeszcze bez pomiarów prototypu.

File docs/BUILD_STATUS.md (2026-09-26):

# What can be built today?

Pinchy is a documented mechanical prototype for **Waveshare ESP32-S3-Touch-LCD-2.1B / SKU 30697**, with an audio integration study. It is not yet a complete voice-assistant kit.

| Area | Included and checked | Still required |
|---|---|---|
| Enclosure | Current CAD/STL, 4 prepared P2S plates, correct B screen seat, four M2 mounts, controls, removable cover, complete legs and D1 base interface | Physical fit, tolerances, latch strength and repeated-use tests |
| Audio placement | Reference component dimensions, fit study and component views | Final holders, microphone opening/channel, speaker gasket/grille integration, battery retention and strain relief |
| Wiring | Proposed netlist, connection drawing and cable routing zones | Actual connector orientation, USB/UART multiplexing tests, confirmed amplifier VCC tap, final wire bends and complete harness clearance |
| Battery | Protected 1S reference and documented connector/charging mismatch | Verified charging-current setting, exact compatible battery harness and polarity; measured operation on the actual board |
| Firmware — TODO | Documentation only; no firmware source code or binaries | A Pinchy board port, reproducible build/flash instructions, tested audio/display integration and a firmware binary |
| Voice and integrations | English/Polish concept films using OpenAI TTS | Wake-word detection, speech recognition, response generation, secure credentials, InPost/mail/calendar integrations and permissions |
| Web explorer | Offline and [public Pages](https://pablo-mano.github.io/Pinchy/) view; rotation, 16 part groups, explosion slider and D1 visualization | Recheck after future site changes |

The films simulate parcel tracking, sending an email and editing a calendar. They do not prove those services are implemented on the device. “Hey Pinchy!” is the intended wake phrase and the spoken line in the film, not a supplied on-device detector.

## Recommended next milestones

1. Print and test the screen and D1 coupons, then validate the enclosure on the physical 30697 board.
2. Select and measure the final audio modules and battery; resolve charge current and the amplifier power point.
3. Bring up I²S RX/TX outside the enclosure, including USB/UART conflicts and safe low speaker volume.
4. Design the missing holders, acoustic seals and complete harness; update CAD and print plates together.
5. Implement a board-specific firmware build and bench test recording/playback/display controls.
6. Add voice services and integrations, with authentication and explicit action handling, then document flashing and setup.
7. Publish measurements: current draw, battery runtime, acoustic quality, thermal behavior and latch endurance.

The old EchoEar rover firmware/safety model is a different project and is intentionally not represented here as Pinchy firmware.

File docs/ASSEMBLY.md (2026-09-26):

# Pinchy assembly guide

Read the [BOM](../electronics/BOM.md), [printing notes](../printing/README.md), [wiring plan](../electronics/WIRING.md) and [build status](BUILD_STATUS.md) first. These steps cover the mechanical prototype; the full voice assistant is not yet a completed kit.

## Tools and preparation

Use small screwdrivers matching your chosen fasteners, flush cutters, tweezers and support-removal tools. Electronics work additionally needs a fine-tip soldering iron, solder/flux, a multimeter and suitable insulation. A current-limited bench supply is useful during electrical bring-up.

Verify the board marking: **Waveshare 30697 / ESP32-S3-Touch-LCD-2.1B**. Keep the factory glass and PCB assembly intact. Print and test the screen coupon and both D1 interface coupons. Remove supports from control guides, rails and the space around the flexure before checking fits.

## Enclosure

1. Place the front bezel face-down on a soft surface. Fit the complete Waveshare module with compressible glass-edge support. Do not press bare glass rigidly against the printed lip. Nominal axial allowances are approximately 0.2 mm at the front and 0.4 mm at the rear, subject to padding compression and the actual unit.
2. Fit the BOOT cap, RESET cap and power slider in their guides. BOOT has one dot, RESET two; the slider has grooves. Confirm full travel and spring return.
3. Bring the central shell over the assembly. Its four supports align with the board's factory M2 mounting nuts.
4. From the open rear, fit **four M2 × 5 mm machine screws** with heads within Ø3.8 × 2 mm. Check actual usable thread depth; nominal engagement is 2.6 mm. Tighten evenly without bending the board or loading the glass.
5. Test the controls and touch surface before closing. The modeled audio insertion order is battery → amplifier → microphone → speaker, but final holders and wiring are not supplied. Do not leave loose conductive modules inside a powered enclosure.
6. Fit the rear service cover and secure the enclosure with **four Ø2.5 × 25 mm screws suitable for plastic**, heads up to Ø4.8 mm. These differ from the M2 board screws. Ordinary M2.5 machine screws are not automatic substitutes.

## Interchangeable D1 base

D1 interface

Keep the current shell and base together as a matched D1 pair. With cables disconnected, begin with the base about 20 mm forward of its seated position, on the display side. Slide it rearward along both rails until the rounded detent seats. The complete legs provide USB clearance between their pairs.

To remove the base, support the shell, press the rear release tab **down and away from the shell**, and slide the base forward toward the display. Do not pry on the claws or use the base to carry the complete device before validating retention.

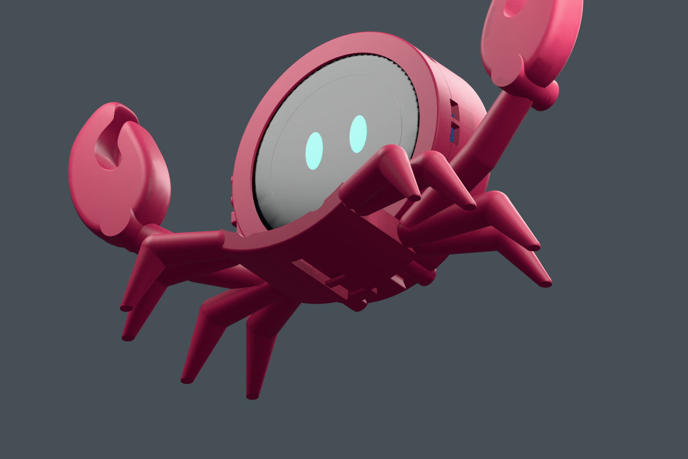
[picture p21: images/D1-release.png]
D1 release


The latch is a printed PLA flexure, not a separately purchased spring. Remove all supports, inspect for cracks/whitening and test repeated release on the coupons. Rail profile clearance is nominally 0.25 mm. Change the interface geometry rather than globally scaling the whole model if adjustment is necessary. [Detailed dimensions in Polish](D1_INTERFACE_PL.md).

## Before electrical integration

Check button return, glass support, screw clearance, cover engagement, USB plug approach and base release with the power off. Verify all J9/J1 conductors and supply conditions on the actual board. Resolve battery charging and the amplifier VCC tap before connecting them. The [wiring document](../electronics/WIRING.md) lists the unverified points explicitly.

Audio mounting, acoustic sealing, strain relief and full harness routing require another integration iteration. Once firmware exists, the release also needs a reproducible flashing guide, recovery method and measured acceptance tests.

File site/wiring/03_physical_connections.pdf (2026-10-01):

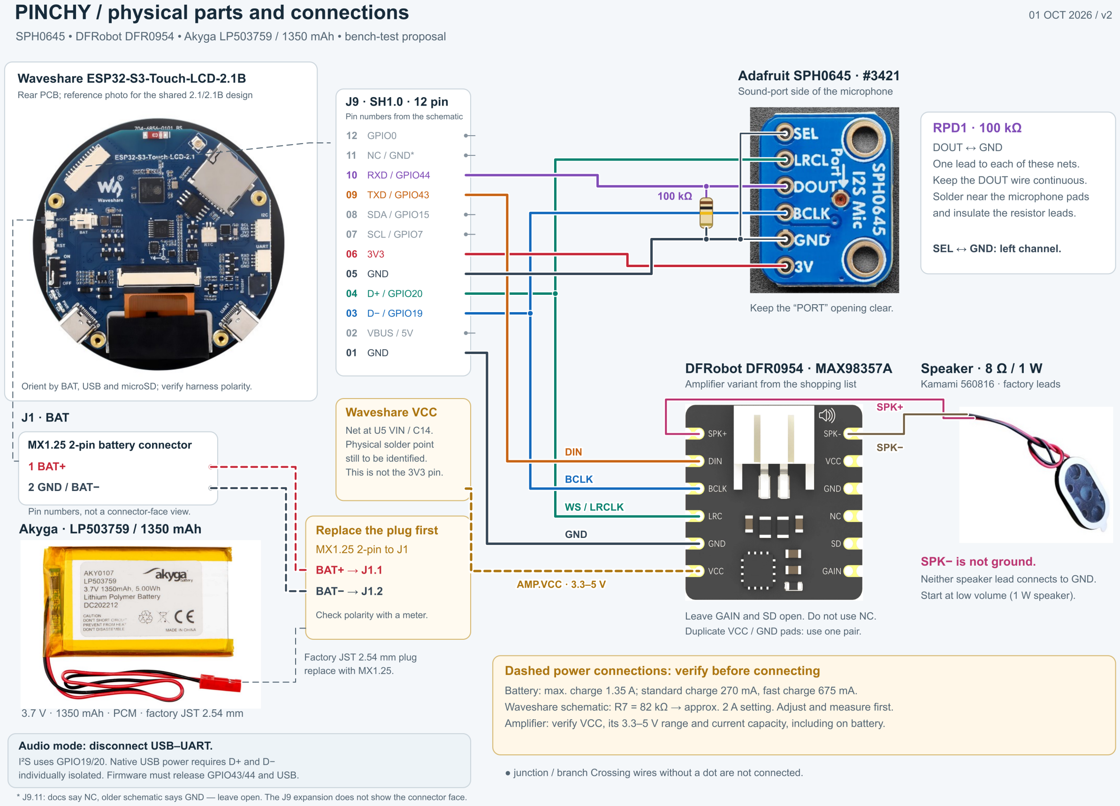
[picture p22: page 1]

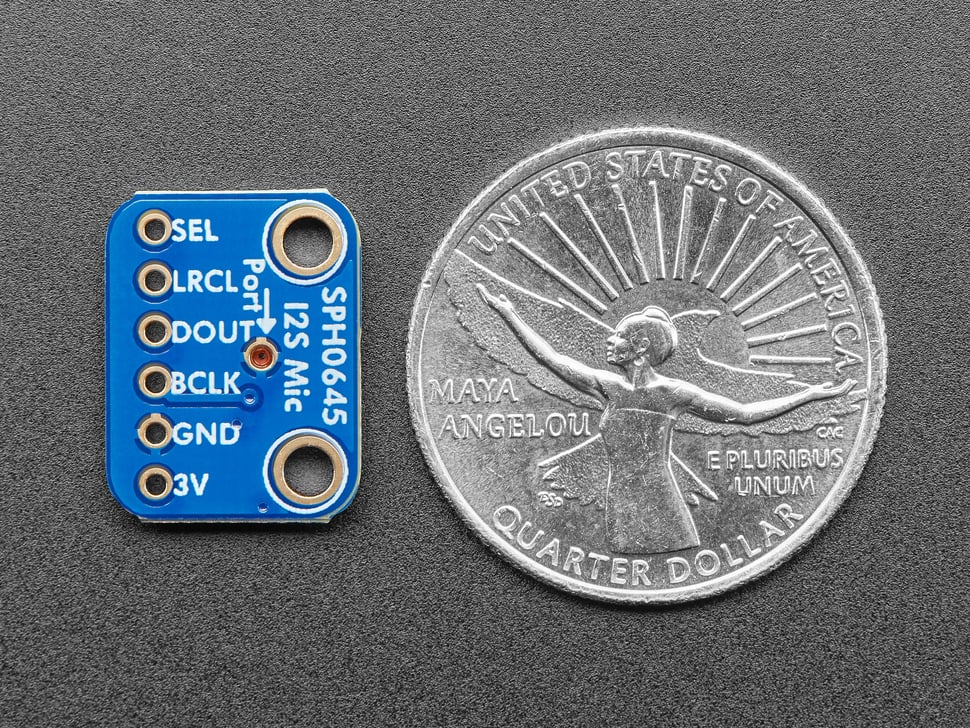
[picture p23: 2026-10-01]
electronics/physical_wiring/assets/microphone-pins.jpg

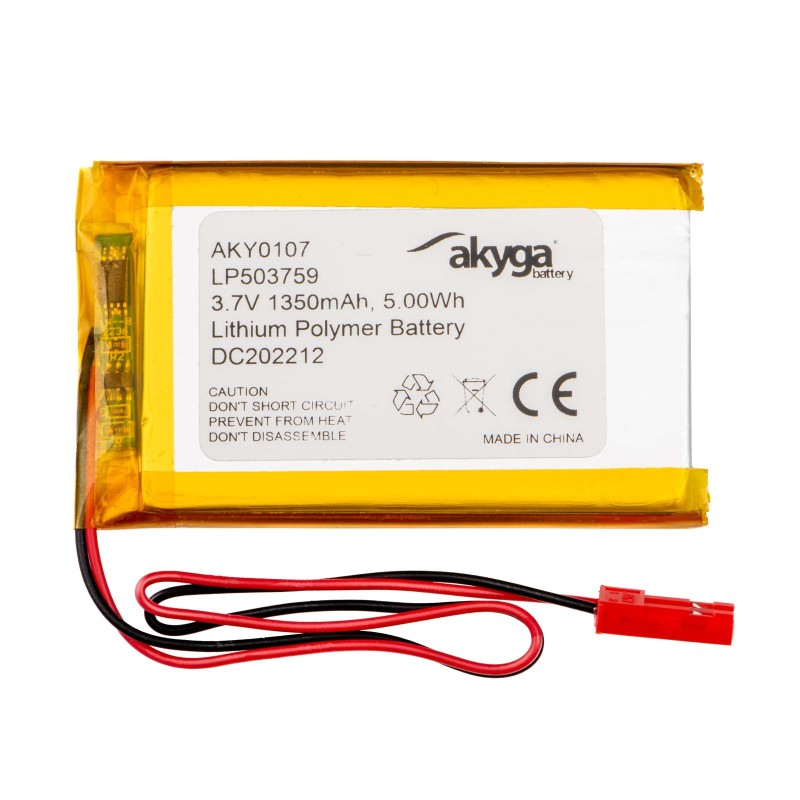
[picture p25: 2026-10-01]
electronics/physical_wiring/assets/aky0107.jpg

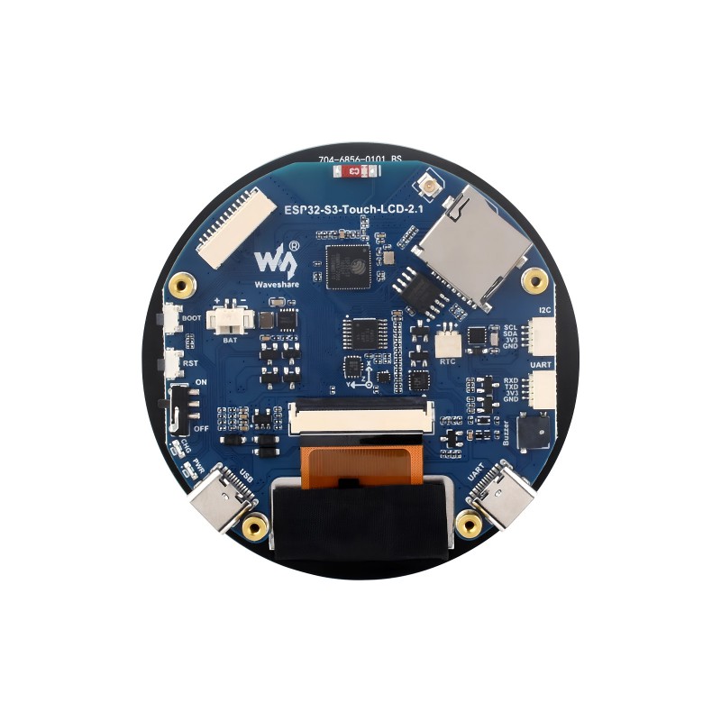
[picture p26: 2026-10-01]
electronics/physical_wiring/assets/waveshare-rear.jpg

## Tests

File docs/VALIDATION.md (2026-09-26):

# Delivery validation

This is a digital-delivery check, not physical qualification of the device.

- All **4 3MF, 15 STL and 13 STEP** files match the current B/D1 output byte for byte. The 3MF ZIP containers pass integrity checks. Existing slicer checks cover bed fit, unchanged scale, P2S 0.4 mm / Generic PLA settings and extrusion at the control tips. No new physical print test was performed during packaging.
- Both final films passed full decoding, duration/frame checks, metadata/attribution checks and audio synchronization checks. Selected final PL/EN frames were visually reviewed. The four packaged videos match the checked exports.
- The offline explorer was opened in a browser and checked for 16 part groups, correct attribution, assembled and D1 presets, autorotation, front-bezel tooltip and microphone selection. The subsequent change only adds source/license notices in About.
- Markdown links are checked within this package; print archives, file sizes and common credential patterns are checked before the ZIP is produced. No API keys or source music MP3 are included.

See the machine-readable [delivery check](../validation.json) and [file hashes](../manifest.json). Live deployment status is recorded separately in [publication.json](../publication.json).

Physical screen fit, audio holders, electrical power/charging, full cable clearance and functioning firmware remain unfinished. See [build status](BUILD_STATUS.md).

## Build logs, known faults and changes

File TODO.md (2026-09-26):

# Pinchy — TODO

## Firmware — deferred / później

**No firmware source code or device binaries are published in this repository.** The current release contains mechanical files, build documentation, the web explorer and concept films. Firmware is a future task, not a prerequisite supplied by this release.

**W repozytorium nie publikujemy na razie żadnego kodu firmware ani binariów do wgrania.** Działające oprogramowanie urządzenia pozostaje TODO; filmy przedstawiają demonstrację koncepcji.

- [ ] Implement and bench-test a board-specific firmware port for Waveshare 30697 / 2.1B.
- [ ] Validate display, touch, side controls and shared I²S audio pins.
- [ ] Add the intended “Hey Pinchy!” interaction and voice services.
- [ ] Implement authenticated parcel, mail and calendar integrations.
- [ ] Publish firmware source and binaries only in a later, explicitly approved release.
- [ ] Add reproducible build, flashing, configuration and recovery instructions with that release.

[Requirements and pin constraints](docs/FIRMWARE.md).

## Hardware integration

- [ ] Validate current screen-fit and D1 coupons on the physical board and printer.
- [ ] Finalize and test audio/battery holders, microphone channel and speaker seal.
- [ ] Verify amplifier power, battery charging current, connector and polarity.
- [ ] Complete the harness and verify connector access, bends and clearance.
- [ ] Measure power consumption, battery runtime, acoustic quality and latch endurance.

[Current build status](docs/BUILD_STATUS.md) · [BOM](electronics/BOM.md) · [Wiring](electronics/WIRING.md).

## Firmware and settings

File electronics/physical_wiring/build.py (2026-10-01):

"""Build the photo-based Pinchy wiring sheet from documented pin/net anchors.

Photographs remain unmodified; nested SVG viewports crop/rotate their presentation.
The drawing is a proposed interconnect, not an electrically validated assembly.
"""
from pathlib import Path
from html import escape
import base64, csv, io, json
from PIL import Image

HERE = Path(__file__).resolve().parent
OUT = HERE.parent
W, H = 2400, 1710
C = dict(gnd='#354656', v3='#c62839', bclk='#1269bc', ws='#09826f',
         mic='#804cb7', din='#c76313', power='#ac7510', spkp='#bb3571', spkn='#715e42')
INK, MUTED, BORDER = '#172b3a', '#546674', '#ccd6dd'
s = []
def put(x): s.append(x)
def text(x,y,t,size=23,color=INK,weight=400,anchor='start',extra=''):
    put(f'<text x="{x}" y="{y}" font-size="{size}" fill="{color}" font-weight="{weight}" text-anchor="{anchor}" {extra}>{escape(t)}</text>')
def lines(x,y,ts,size=22,color=MUTED,step=30):
    for i,t in enumerate(ts): text(x,y+i*step,t,size,color)
def rect(x,y,w,h,fill='white',stroke=BORDER,r=16,dash=''):
    put(f'<rect x="{x}" y="{y}" width="{w}" height="{h}" rx="{r}" fill="{fill}" stroke="{stroke}" stroke-width="2" stroke-dasharray="{dash}"/>')
def group(net): put(f'<g class="net" data-net="{net}"><title>{escape(NETS[net]["description"])}</title>')
def end(): put('</g>')
def line(points,col,width=5,dash=False,halo=True):
    pts=' '.join(f'{x:.1f},{y:.1f}' for x,y in points)
    if halo: put(f'<polyline points="{pts}" fill="none" stroke="white" stroke-width="{width+5}" stroke-linejoin="round" stroke-linecap="round"/>')
    put(f'<polyline points="{pts}" fill="none" stroke="{col}" stroke-width="{width}" stroke-linejoin="round" stroke-linecap="round"'+(' stroke-dasharray="12 9"' if dash else '')+'/>')
def dot(x,y,col,r=6):
    put(f'<circle cx="{x:.1f}" cy="{y:.1f}" r="{r}" fill="{col}" stroke="white" stroke-width="2"/>')
def label(x,y,t,col):
    text(x,y,t,21,col,600,extra='paint-order="stroke" stroke="white" stroke-width="7" stroke-linejoin="round"')
def photo(name,x,y,w,h,crop=None,rotate=False):
    p=HERE/'assets'/name
    im=Image.open(p)
    # Convert unsupported WebP storage only; pixel geometry is retained.
    if p.suffix=='.webp':
        b=io.BytesIO(); im.save(b,format='PNG'); data=b.getvalue(); mime='image/png'
    else: data=p.read_bytes(); mime='image/jpeg'
    uri='data:'+mime+';base64,'+base64.b64encode(data).decode()
    iw,ih=im.size
    cx,cy,cw,ch=crop or (0,0,iw,ih)
    if rotate:
        put(f'<svg x="{x}" y="{y}" width="{w}" height="{h}" viewBox="0 0 {ch} {cw}"><g transform="translate(0 {cw}) rotate(-90)">')
        put(f'<svg width="{cw}" height="{ch}" viewBox="{cx} {cy} {cw} {ch}">')
    else: put(f'<svg x="{x}" y="{y}" width="{w}" height="{h}" viewBox="{cx} {cy} {cw} {ch}">')
    put(f'<image width="{iw}" height="{ih}" href="{uri}"/>')
    put('</svg>')
    if rotate: put('</g></svg>')

NETS = {
 'v3':dict(label='3V3 · microphone',description='J9.6 3V3 → MIC 3V. Microphone supply: 3.3 V.',endpoints=['J9.6','MIC.3V']),
 'gnd':dict(label='GND · common ground',description='J9.5 → MIC.GND; MIC.SEL → MIC.GND. J9.1 → AMP.GND. BAT− shares ground through the board.',endpoints=['J9.5','MIC.GND','MIC.SEL','J9.1','AMP.GND']),
 'bclk':dict(label='BCLK · GPIO19',description='J9.3 D−/GPIO19 → MIC.BCLK and AMP.BCLK. A dot marks the shared clock branch.',endpoints=['J9.3','MIC.BCLK','AMP.BCLK']),
 'ws':dict(label='WS / LRCLK · GPIO20',description='J9.4 D+/GPIO20 → MIC.LRCL and AMP.LRC. Both modules share the word clock.',endpoints=['J9.4','MIC.LRCL','AMP.LRC']),
 'mic':dict(label='DOUT · GPIO44 + 100 kΩ',description='MIC.DOUT → J9.10 RXD/GPIO44. RPD1 is a 100 kΩ pull-down between DOUT and GND, not a series resistor.',endpoints=['MIC.DOUT','J9.10','RPD1.1']),
 'din':dict(label='DIN · GPIO43',description='J9.9 TXD/GPIO43 → AMP.DIN. Audio data travels from the ESP32 to the amplifier.',endpoints=['J9.9','AMP.DIN']),
 'power':dict(label='Power · verify first',description='BAT+ → J1.1; BAT− → J1.2 after replacing the connector and adjusting charging. Connect Waveshare VCC to AMP.VCC only after locating and measuring the supply point.',endpoints=['BAT.+','J1.1','BAT.-','J1.2','WAVE.VCC_UNVERIFIED','AMP.VCC']),
 'spkp':dict(label='SPK+ · speaker',description='AMP.SPK+ → the red speaker lead. This is a bridge output, not ground.',endpoints=['AMP.SPK+','SPK.+']),
 'spkn':dict(label='SPK− · speaker',description='AMP.SPK− → the black speaker lead. Do not connect it to GND.',endpoints=['AMP.SPK-','SPK.-']),
}

put(f'<svg xmlns="http://www.w3.org/2000/svg" width="{W}" height="{H}" viewBox="0 0 {W} {H}" role="img" aria-labelledby="title desc">')
put('<title id="title">Pinchy — physical modules, pins and connections</title><desc id="desc">Photo wiring diagram for Waveshare ESP32-S3-Touch-LCD-2.1B, SPH0645, DFRobot DFR0954, an 8 ohm 1 W speaker and Akyga AKY0107 battery. Dashed power connections require verification. A text connection table follows the drawing.</desc>')
put('<style>text{font-family:Arial,"DejaVu Sans",sans-serif}.net{transition:opacity .15s}.net.dim{opacity:.10}.net:hover{filter:drop-shadow(0 0 2px #708090)}</style>')
put(f'<rect width="{W}" height="{H}" fill="#f4f7fa"/>')
text(56,68,'PINCHY / physical parts and connections',42,weight=700)
text(58,112,'SPH0645  •  DFRobot DFR0954  •  Akyga LP503759 / 1350 mAh  •  bench-test proposal',24,MUTED)
text(2338,67,'01 OCT 2026 / v2',22,MUTED,anchor='end')
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

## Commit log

2026-09-26 Publish Pinchy mechanical prototype, explorer and build documentation; firmware TODO
    [00_B_fit_ring_71p8.step, 00_B_fit_ring_71p8.stl, 00_D1_body_coupon.step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]
2026-09-26 Use current raspberry smile in the exploded-view display
2026-10-01 Add photo-based wiring diagram with interactive view and A3 PDF
    [03_physical_connections.csv]
2026-10-01 Unify Pinchy explorers with shared navigation and English wiring UI
    [03_physical_connections.csv]
